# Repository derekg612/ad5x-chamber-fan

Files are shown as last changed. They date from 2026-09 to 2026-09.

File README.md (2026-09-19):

# AD5X Chamber Regulator

Three interchangeable builds of the same chamber controller, selected by PlatformIO environment:

| Environment | Board | Local UI | Fan control |
| --- | --- | --- | --- |
| `seeed_xiao_esp32c3` | Xiao ESP32-C3 | External 128x64 OLED + 2 buttons | On/off |
| `waveshare_esp32s3_touch_lcd_147` | Waveshare ESP32-S3-Touch-LCD-1.47 | Built-in 172x320 touchscreen | PWM speed control |
| `esp32_c3_oled_042` | Generic ESP32-C3 with 0.42" OLED | Onboard 72x40 OLED + 2 buttons | PWM speed control |

The 0.42" OLED build can also toggle the printer's chamber light over the network -- press both buttons at once.

All three share the same thermistor logic, Wi-Fi setup flow, and web UI. Build/upload a specific one with `pio run -e <environment> -t upload`; the Xiao environment is the default when no `-e` is given.

Wiring docs: [circuit-schematic.md](docs/circuit-schematic.md) (Xiao), [touch-lcd-schematic.md](docs/touch-lcd-schematic.md) (touchscreen), [c3-oled-042-schematic.md](docs/c3-oled-042-schematic.md) (0.42" OLED).

## Common behavior

On first boot, connect to the `AD5X-Chamber-Setup` Wi-Fi network using password `chamber123`, then follow the setup page to select the printer's Wi-Fi network. The saved connection is reused on later boots. Open the IP address printed to the serial monitor at 115200 baud, or shown on the display. Settings are saved in nonvolatile storage.

The fan turns on at `setpoint + upper threshold` and turns off at `setpoint - lower threshold`. A disconnected or out-of-range thermistor turns the fan on as a fail-safe.

## Xiao ESP32-C3 build (`seeed_xiao_esp32c3`)

- Xiao ESP32-C3, powered from the printer display's USB-A port (5 V/GND only)
- 10 kOhm NTC thermistor, Beta 3950
- 10 kOhm fixed resistor
- 24 V fan (no PWM input) mounted in the back panel, switched on/off through a 2N2222A NPN transistor (or BC337) on its ground return (return wire routed forward with the display ribbon cable), with a flyback diode across the fan
- 0.96" I2C SSD1306 128x64 OLED display
- 2 momentary buttons for local setpoint adjustment

Wire the thermistor and fixed resistor as a divider from 3.3 V to GND, with the midpoint on `D0`. The firmware assumes the thermistor is the high-side component and the fixed resistor is the low-side component. Connect the 2N2222A base to `D1` through a 330 Ohm resistor, share grounds, and power the fan continuously from an appropriate external 24 V supply. Do not power the fan through the Xiao.

Connect the OLED over I2C to `D4` (SDA) and `D5` (SCL), powered from `3V3`. Wire the two momentary buttons between `D2`/`D3` and `GND`; the firmware uses internal pull-ups, so no external resistors are needed. One button raises the setpoint, the other lowers it, in 0.5 degree C steps, with the change reflected immediately on the OLED and saved to nonvolatile storage.

## Waveshare ESP32-S3-Touch-LCD-1.47 build (`waveshare_esp32s3_touch_lcd_147`)

- Waveshare ESP32-S3-Touch-LCD-1.47 (built-in 172x320 touchscreen), powered from the printer display's USB-A port via its own USB-C port (5 V/GND only)
- 10 kOhm NTC thermistor, Beta 3950
- 10 kOhm fixed resistor
- 2-wire 24 V fan (0.29 A @ 24 V) mounted in the back panel, PWM speed-controlled through a 2N2222A NPN transistor (or BC337) on its ground return, with a 1N5819 Schottky across the fan

There's no separate OLED or physical buttons in this build -- the board's own display and capacitive touchscreen replace both. The UI runs in portrait orientation with the USB-C port at the bottom of the screen; two on-screen `-`/`+` buttons adjust the setpoint by 0.5 degree C per tap, the same step size and persistence behavior as the button build. Wire the thermistor to `GPIO4` and the 2N2222A base (through a 220 Ohm resistor) to `GPIO5`.

Unlike the Xiao build's on/off control, fan speed ramps proportionally between `setpoint - lower threshold` (idle) and `setpoint + upper threshold` (the configured maximum), with a duty floor so the fan doesn't sit below its stall speed. A maximum-fan-speed cap is available on the web settings page. All the fan drive parameters -- PWM frequency, duty floor, and an on/off fallback -- are `#define`s at the top of [src/main_s3touch.cpp](src/main_s3touch.cpp). See [docs/touch-lcd-schematic.md](docs/touch-lcd-schematic.md) for the full pinout, component sizing rationale, and the display/touch pins that are reserved internally.

## ESP32-C3 OLED 0.42" build (`esp32_c3_oled_042`)

- Generic ESP32-C3 board with an onboard 0.42" 72x40 SSD1306 OLED, powered from the printer display's USB-A port (5 V/GND only)
- 100 kOhm NTC thermistor, Beta 3950
- 100 kOhm fixed resistor
- 2-wire 24 V fan (0.29 A @ 24 V), PWM speed-controlled through a 2N2222A NPN transistor (or BC337) on its ground return, with a 1N5819 Schottky across the fan
- 2 momentary buttons for local setpoint adjustment and printer LED control

Same PWM fan control and `#define` knobs as the touchscreen build, but with a compact portrait display (mounted with the USB port on the left) and physical buttons. Thermistor on `IO2`, transistor base (via 220 Ohm) on `IO20`, and the setpoint up/down buttons on `IO1` and `IO4`. `IO20` is UART0's RX pin, which is free because this environment sends `Serial` over the board's native USB instead. The OLED occupies `IO5`/`IO6` internally (the board reference says `IO8`/`IO9`; see the schematic doc if the panel stays blank).

#### Printer LED toggle

Pressing **both buttons at once** toggles the printer's chamber light and shows the new state on the OLED for a moment. Neither button moves the setpoint while the other is down, and one long two-button press toggles exactly once.

Stock AD5X firmware does not expose Moonraker, so this talks to Flashforge's legacy command socket on TCP 8899, the same protocol as the `ad5x_send_command.py` helper script: commands framed with a leading `~` and CRLF, replies terminated by `ok`. Each toggle takes control (`M601 S1`), sends `M146 r255 g255 b255 F0` or `M146 r0 g0 b0 F0`, then hands control back (`M602`) so the printer's touchscreen is not left locked out. The printer will not report its light state back, so the firmware tracks what it last sent and persists it across reboots; if the light is changed at the printer, the first press afterwards may be a no-op.

The printer's hostname and port are on the web settings page, defaulting to `ad5x.lan:8899`. A failed toggle leaves the setting untouched and shows `fail` on the panel, with the detail on the serial monitor.

### Enclosure

[hardware/generate_c3_oled_case.py](hardware/generate_c3_oled_case.py) generates a two-part snap-fit case for this build:

```
~/.pythonenvs/stl/bin/python3 hardware/generate_c3_oled_case.py
```

It writes `case_bottom.stl` and `case_top.stl` alongside the script. The board is held without soldered headers, resting on a perimeter ledge and pressed down by pads on the lid, with 7 mm of headroom so the 2N2222A can lie flat on the PCB. Openings: USB-C on one end, a 6 mm circular cable hole in the middle of the tray floor -- the back panel -- for the fan return, ground bond, thermistor pair and button wires, and a window over the OLED. That hole opens into the relief under the board, so those wires solder to pads on the PCB's underside and drop straight out the back; there is only 1.2 mm of height in there, so they cannot run sideways first. Every dimension is a named constant at the top of the script, and `check_parameters()` asserts the ones that quietly ruin a print (wall left behind the snap groove, snap deflection, material bridging the wall openings, TO-92 headroom).

[hardware/preview_case.py](hardware/preview_case.py) renders the result for inspection:

```
~/.pythonenvs/stl/bin/python3 hardware/preview_case.py
```

It writes `preview_iso.png` (shaded views of each part plus an exploded view) and `preview_sections.png` (cuts through the assembled case). The section views are the useful ones -- they show the lip seated in the rebate, the snap ridge in its groove, the PCB on its ledge, and the material bridging the wall openings. Requires `matplotlib` in the same environment.

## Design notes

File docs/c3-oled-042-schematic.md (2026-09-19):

# ESP32-C3 OLED 0.42" Build

A generic ESP32-C3 board with an onboard 0.42" 72x40 SSD1306 OLED
([board reference](https://www.espboards.dev/esp32/esp32-c3-oled-042/)), with two external momentary buttons for setpoint adjustment. The fan circuit is identical to the touchscreen build -- 2N2222A (or BC337) low-side switch, 220 Ohm base resistor, 1N5819 Schottky, PWM speed control -- so see [touch-lcd-schematic.md](touch-lcd-schematic.md) for the component sizing rationale and [circuit-schematic.md](circuit-schematic.md) for the ground-bonding requirement. Both apply here unchanged.

## Pin budget

This board is unusually tight: of its 13 broken-out GPIOs, only IO0, IO1, IO3 and IO10 are free of strapping, JTAG or UART duty. The build uses:

| GPIO | Use | Notes |
| --- | --- | --- |
| IO1 | Setpoint-up button | Internal pull-up |
| IO2 | Thermistor divider midpoint | ADC1_CH2. Strapping pin -- see below. |
| IO4 | Setpoint-down button | Internal pull-up. JTAG TMS, free because JTAG goes over USB. |
| IO20 | 2N2222A base (via 220 Ohm) | PWM output. UART0 RX, free because Serial goes over USB. |

Reserved, do not reuse:

| GPIO | Function |
| --- | --- |
| IO5 | OLED I2C SDA (also JTAG TDI) |
| IO6 | OLED I2C SCL (also JTAG TCK) |
| IO8, IO9 | Strapping -- IO9 selects download mode at reset |
| IO18, IO19 | Native USB (the USB-C port) |

IO0, IO3, IO7, IO10 and IO21 are unused.

The board reference puts the OLED on IO8/IO9, but on the board this was built with it is wired to IO5/IO6, and boards sold under this name vary. If the panel stays blank, set `OLED_SDA_PIN`/`OLED_SCL_PIN` in `src/main_c3oled.cpp` to 8/9 and try again.

IO4, IO5 and IO6 being JTAG pins is harmless: the C3 routes JTAG through its built-in USB by default, so they behave as ordinary GPIO. IO8/IO9 are left unused, but they are still strapping pins, so don't add anything there that could pull them low at reset.

**Thermistor on IO2:** IO2 is listed as a strapping pin, but per Espressif's [hardware design guidelines](https://docs.espressif.com/projects/esp-hardware-design-guidelines/en/latest/esp32c3/schematic-checklist.html) it does not actually select the boot mode -- they only recommend pulling it high to guard against glitches. The divider holds it partway instead (about 1.65 V at 25 C, rising as the chamber warms), so this should be fine, but if boots are ever unreliable, move the thermistor to IO3 (also ADC1) and change `THERMISTOR_PIN`.

**Fan on IO20:** the USB-C port is wired to the C3's native USB, so flashing and the serial monitor never touch UART0 (IO20/IO21). The `esp32_c3_oled_042` environment sets `ARDUINO_USB_CDC_ON_BOOT=1` so that `Serial` also goes over USB, which leaves IO20 free. IO20 was picked over IO21 because it is an input during boot: IO21 is UART0 TX, which idles high and carries the boot log at every reset, so the fan would run and chatter for a moment before the firmware takes over. If the fan still twitches at power-up on IO20, add a 4.7-10 kOhm resistor from IO20 to GND.

## Wiring

```text
                         AD5X MAINBOARD AUX FAN PORT (BACK PANEL)

             +24 V  o----[ 1 A fuse ]----+--------------------+
                                         |                    |
                                         |                 +--+--+
                                         |                 | 24 V |
                                         |                 | FAN  |
                                         |                 +--+--+
                                         |                    |
                                         |                    +------|<|------+
                                         |                    |    1N5819     |
                                         |                    |               |
                                         |                              C  +---+---+
                                         |          IO20 --[220R]-------B  |2N2222A|
                                         |                              E  +---+---+
                                         |                                    |
             GND   o--------------------+------------------------------------+--- GND

             2N2222A (TO-92): E-B-C left to right, flat face toward you.

                         THERMISTOR INPUT (3.3 V ADC)

             3V3 o----[ 100 kOhm NTC, Beta 3950 ]----+----[ 100 kOhm ]----o GND
                                                      |
                                                      +--------------------- IO2

                         SETPOINT BUTTONS (momentary, to GND)

             IO1 o----[ momentary button ]---- GND     (setpoint up)
             IO4 o----[ momentary button ]---- GND     (setpoint down)
             Internal pull-ups enabled in firmware; no external resistors needed.

                         POWER

             Printer display USB-A +5 V  o------- board 5 V / VBUS
             Printer display USB-A GND   o------- board GND
```

## Display

The board is mounted in portrait with the USB port on the left and the screen facing you, so the 72x40 panel is drawn a quarter turn round as 40 pixels wide by 72 tall:

```
  NOW
  32.4
  SET
  35.0
  FAN
  45%
192.168.
  1.42
```

The current temperature is the largest reading (`fault` if the thermistor reading is invalid). Below it are the setpoint and the fan duty (`idle` when off), each with a tiny label above its value, since 40 pixels is only six characters wide in the value font. The IP address is split after its second octet so that even `255.255.255.255` fits.

Pressing both buttons shows `LIGHT` over `...` while the command is sent, then `ON`, `OFF`, or `fail` if the printer didn't reply.

If the text comes out upside down, the panel is mounted the other way round on your board: change `U8G2_R3` to `U8G2_R1` in the display constructor in `src/main_c3oled.cpp`.

## Important electrical notes

- Same ground-bonding requirement as the other builds: run a dedicated ground wire from the AD5X mainboard's real power ground to this board's ground bus. Do not rely on the display ribbon cable's ground pin.
- The 1N5819 flyback diode is required, installed directly across the fan.
- The 100 kOhm divider has a source impedance of around 50 kOhm, which is high enough for the ADC's sampling capacitor and fan-switching noise to pull readings around. A 100 nF ceramic capacitor from IO2 to GND, placed at the board, steadies it.
- An undriven IO20 (at boot, or if the firmware hangs) turns the fan off, not on. The firmware's sensor-fault fail-safe (full speed when the thermistor reading is invalid) still applies.
- Do not connect 24 V to any board GPIO, `3V3`, or `5V` pin.

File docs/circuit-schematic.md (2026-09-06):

# AD5X Chamber Regulator Circuit

This schematic uses the AD5X 24 V auxiliary fan supply, a plain (non-PWM) 24 V fan mounted in the back panel, a 2N2222A NPN transistor (or BC337 -- interchangeable here) as an on/off low-side switch, the printer display's USB-A port for 5 V/GND to the Xiao ESP32-C3, a 0.96" I2C SSD1306 128x64 OLED, and two momentary buttons for local setpoint adjustment.

The fan has no speed control input, so the Xiao switches it fully on or off instead of ramping speed. The fan's `+24 V` lead stays at the back panel, fused. The fan's `GND` return is run forward from the back panel (alongside the display ribbon cable) to the Xiao's control area, where the 2N2222A interrupts it to switch the fan. Because the 2N2222A is now switching real motor current, a flyback diode across the fan is required again to clamp the inductive kick when the transistor turns off.

The Xiao is powered from the printer display's USB-A port (5 V and GND only; D+/D- are unused) instead of a buck converter, since the display port already sits at logic-compatible 5 V.

```text
                         AD5X MAINBOARD AUX FAN PORT (BACK PANEL)
                         (VERIFY POLARITY AND VOLTAGE)

             +24 V  o----[ 1 A fuse ]----+--------------------+
                                         |                    |
                                         |                 +--+--+
                                         |                 | 24 V |
                                         |                 | FAN  |
                                         |                 +--+--+
                                         |                    |
                                         |                    +------|<|------+
                                         |                    |   flyback     |
                                         |                    |   diode       |
                                         |                    |               |
                                         |                    |  fan GND, run forward
                                         |                    |  alongside display
                                         |                    |  ribbon cable
                                         |                    |               |
                                         |                              C  +---+---+
                                         |            Xiao D1 --[330R]--B  |2N2222A|
                                         |                              E  +---+---+
                                         |                                  (or BC337)
                                         |                                    |
             GND   o--------------------+------------------------------------+--- GND

                         PRINTER DISPLAY USB-A PORT

             USB-A +5 V  o---------------------------------- Xiao 5V / VBUS
             USB-A GND   o---------------------------------- Xiao GND
             (D+/D- not connected)

                         THERMISTOR INPUT (3.3 V ADC)

             Xiao 3V3 o----[ 10 kOhm NTC, Beta 3950 ]----+----[ 10 kOhm ]----o Xiao GND
                                                         |
                                                         +---------------------- Xiao D0

             Optional: 100 nF capacitor from D0 to Xiao GND, placed near the Xiao.

                         0.96" I2C SSD1306 128x64 OLED

             OLED VCC  o---------------------------------- Xiao 3V3
             OLED GND  o---------------------------------- Xiao GND
             OLED SDA  o---------------------------------- Xiao D4
             OLED SCL  o---------------------------------- Xiao D5

                         SETPOINT BUTTONS (momentary, to GND)

             Xiao D2 o----[ momentary button ]---- GND     (setpoint up)
             Xiao D3 o----[ momentary button ]---- GND     (setpoint down)
             Internal pull-ups enabled in firmware; no external resistors needed.
```

## Connections

| Circuit point | Connect to |
| --- | --- |
| AD5X auxiliary fan `+24 V` | Fuse input, fan `+24 V` |
| Fan `GND` (motor return) | 2N2222A collector (wire routed with the display ribbon cable) |
| 2N2222A emitter | Common ground |
| Xiao `D1` | 330 Ohm base resistor, then 2N2222A base |
| Flyback diode cathode | Fan `+24 V` |
| Flyback diode anode | Fan `GND` / 2N2222A collector |
| Printer display USB-A `+5 V` | Xiao `5V`/`VBUS` pin |
| Printer display USB-A `GND` | Xiao `GND` |
| Thermistor divider midpoint | Xiao `D0` |
| OLED `VCC` | Xiao `3V3` |
| OLED `GND` | Xiao `GND` |
| OLED `SDA` | Xiao `D4` |
| OLED `SCL` | Xiao `D5` |
| Setpoint-up button | Xiao `D2` to `GND` |
| Setpoint-down button | Xiao `D3` to `GND` |

## Important electrical notes

- Measure the AD5X fan connector with a multimeter before wiring. Confirm it is approximately 24 V DC and identify polarity; do not rely on connector appearance alone.
- The 2N2222A (or BC337 -- either works here) is a plain NPN switch, not a logic-level MOSFET, so there's no gate-threshold uncertainty at 3.3 V. A TO-92 part marked "2N2222A" is really a PN2222A/P2N2222A equivalent, about 600 mA and 40 V, which is ample for this load. The 330 Ohm base resistor gives a forced beta of roughly 10-20 at typical small-fan currents (100-300 mA), enough to saturate it reliably. For the 0.29 A fan used in the touchscreen build, drop the base resistor to 220 Ohm for proper saturation margin.
- Pinout of the TO-92 2N2222A in hand: **E-B-C left to right**, flat face toward you with the leads pointing down (mirrors to C-B-E viewed from the rounded back). If you substitute a BC337, re-check first -- TO-92 pin assignments vary between part families and manufacturers, and a reversed emitter/collector still conducts weakly, so it appears half-working while running hot.
- The flyback diode must be rated for the fan's current and installed directly across the fan, reverse-biased during normal operation. This is required now that the 2N2222A switches real motor current, not just a logic signal.
- Verify the display USB-A port actually provides 5 V (not 3.3 V or a data-only pass-through). Do not add other 5 V loads to this port beyond the Xiao and OLED.
- **Do not rely on the display ribbon cable's ground pin as the system's common ground.** Measured continuity between the USB-A GND and the AD5X mainboard ground through the display cable can be tens of ohms (a thin signal-return trace, not a real ground bond) — nowhere near low enough to carry the fan's switched current or hold a stable ADC reference. Run a dedicated ground wire, comparable gauge to the fan wiring, directly from the AD5X mainboard's real power ground (the same GND the aux fan port uses) forward to the Xiao's ground bus, where it ties together the 2N2222A emitter, thermistor return, and OLED GND. That wire's low resistance dominates over the weak ribbon-cable path and establishes the actual common ground the circuit needs; the USB-A port then only needs to supply `5V`.
- Do not connect 24 V to any Xiao GPIO, `3V3`, `5V`, or `D+`/`D-` pin.
- Keep the 24 V fan wiring physically separate from the thermistor, OLED, and button wiring.
- The OLED and both buttons run at 3.3 V logic; do not substitute a 5 V-only OLED module without level shifting.
- Unlike the earlier PWM design, an undriven `D1` (GPIO low, at boot or if the firmware hangs) turns the 2N2222A off, which turns the fan off — there is no hardware fail-safe defaulting to full speed. The firmware's fail-safe (forcing the fan on when the thermistor reading is invalid) only covers sensor faults, not a hung MCU. The firmware turns the fan on if the thermistor reading is out of range, so a sensor or wiring fault fails toward ventilation.

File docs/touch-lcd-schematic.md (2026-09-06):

# Waveshare ESP32-S3-Touch-LCD-1.47 Build

This variant replaces the Xiao's external OLED and two physical buttons with the Waveshare ESP32-S3-Touch-LCD-1.47's built-in 172x320 capacitive touchscreen, and drives the fan with PWM speed control rather than plain on/off. The fan circuit topology is the same as the Xiao build (2N2222A or BC337 low-side switch on the fan's ground return, flyback diode, dedicated ground bonding wire), but the base resistor and diode are sized for PWM here -- see [Fan drive](#fan-drive-pwm-speed-control) below. The ground-bonding warning in [circuit-schematic.md](circuit-schematic.md) applies unchanged.

## Reserved pins (do not reuse)

These are wired internally on the board to the display and touch controller, confirmed from Waveshare's own Arduino example and community demo code for this exact board:

| Signal | GPIO |
| --- | --- |
| LCD MOSI | 39 |
| LCD SCK | 38 |
| LCD CS | 21 |
| LCD DC | 45 |
| LCD RST | 47 |
| LCD backlight | 46 |
| Touch SDA | 42 |
| Touch SCL | 41 |
| Touch RST | 47 (shared with LCD RST) |
| Touch INT | 48 |
| BOOT button | 0 |
| Battery ADC (unused here, no battery in this build) | 12 |

The module is an ESP32-S3R8 (8 MB octal PSRAM) with 16 MB flash, native USB (no separate USB-UART bridge chip), confirmed via `platformio.ini`'s `qio_opi` memory type setting.

## Our wiring (fan + thermistor)

```text
                         AD5X MAINBOARD AUX FAN PORT (BACK PANEL)
                         (VERIFY POLARITY AND VOLTAGE)

             +24 V  o----[ 1 A fuse ]----+--------------------+
                                         |                    |
                                         |                 +--+--+
                                         |                 | 24 V |
                                         |                 | FAN  |
                                         |                 +--+--+
                                         |                    |
                                         |                    +------|<|------+
                                         |                    |   flyback     |
                                         |                    |   diode       |
                                         |                    |               |
                                         |                    |  fan GND, run forward
                                         |                    |  to the board
                                         |                    |               |
                                         |                              C  +---+---+
                                         |         GPIO5 --[220R]--------B  |2N2222A|
                                         |                              E  +---+---+
                                         |                                  (or BC337)

             2N2222A (TO-92) physical pinout -- flat/marked face toward you,
             leads pointing down. Confirmed on the actual parts in hand:

                       +-------+
                       |2N2222A|         E (left)   -> common ground
                       +-------+         B (middle) -> 220R -> GPIO5
                        |  |  |          C (right)  -> fan GND return
                        E  B  C

             Viewed from the rounded back instead, this order mirrors to C-B-E.
                                         |                                    |
             GND   o--------------------+------------------------------------+--- GND

                         THERMISTOR INPUT (3.3 V ADC)

             3V3 o----[ 10 kOhm NTC, Beta 3950 ]----+----[ 10 kOhm ]----o GND
                                                     |
                                                     +---------------------- GPIO4

             Optional: 100 nF capacitor from GPIO4 to GND, placed near the board.

                         POWER (from printer display USB-A, via this board's USB-C)

             USB-A +5 V  o---------------------------------- board USB-C (VBUS)
             USB-A GND   o---------------------------------- board USB-C (GND)
```

## Connections

| Circuit point | Connect to |
| --- | --- |
| AD5X auxiliary fan `+24 V` | Fuse input, fan `+24 V` |
| Fan `GND` (motor return) | 2N2222A collector |
| 2N2222A emitter | Common ground |
| Board `GPIO5` | 220 Ohm base resistor, then 2N2222A base |
| 1N5819 Schottky cathode | Fan `+24 V` |
| 1N5819 Schottky anode | Fan `GND` / 2N2222A collector |
| Thermistor divider midpoint | Board `GPIO4` |
| Printer display USB-A `+5 V` / `GND` | Board's own USB-C connector |

## UI

The screen runs in portrait orientation (172 wide x 320 tall) with the USB-C port at the bottom. It shows the current temperature, the setpoint, and fan state, with two large on-screen buttons at the bottom of the screen (`-` and `+`) that nudge the setpoint by 0.5 degree C per tap -- the same step size, debounce behavior, and NVS persistence as the physical buttons in the Xiao build. The web UI (same page/settings routes as the Xiao build) is also still available over Wi-Fi.

**Orientation is a firmware assumption, not a confirmed fact** -- `DISPLAY_ROTATION` in `src/main_s3touch.cpp` is set to `2` based on the vendor demo's default (`0`) placing the USB-C at the top; rotating 180 degrees should put it at the bottom. Verify this on first boot: if the UI renders upside down, change `DISPLAY_ROTATION` to `0` and re-flash. The touch driver is initialized with the same rotation value so touch coordinates stay aligned with what's drawn.

## Fan drive (PWM speed control)

The fan is a 2-wire 24 V unit rated 0.29 A @ 24 V over a 16-26.4 V supply range, and its speed is controlled by chopping its supply with the 2N2222A (or BC337) at 25 kHz. Speed ramps proportionally between `setpoint - lower threshold` (idle) and `setpoint + upper threshold` (the configured maximum), with a 25% duty floor so the fan doesn't sit below its stall speed. All the knobs are `#define`s at the top of `src/main_s3touch.cpp`:

| Define | Default | Purpose |
| --- | --- | --- |
| `FAN_PWM_ENABLED` | `1` | Set to `0` for plain on/off switching |
| `FAN_PWM_FREQUENCY_HZ` | `25000` | Above the audible band; lower it to cut switching loss |
| `FAN_PWM_RESOLUTION_BITS` | `8` | LEDC duty resolution (0-255) |
| `FAN_MIN_DUTY_PERCENT` | `25` | Stall floor once the fan is asked to run |
| `FAN_SPEED_CAP_MIN_PERCENT` | `25` | Lower bound of the web UI's max-speed setting |

Unlike the earlier 4-wire PWM design, this drive is **not** inverted: `GPIO5` high turns the 2N2222A on and powers the fan, so duty maps straight through.

### Component choices for PWM

- **2N2222A (TO-92), or BC337**: at 0.29 A and a 26.4 V worst-case rail these are the only suitable NPNs from the on-hand parts, and they're interchangeable in this circuit. The 2N2222A is the default here because it's a purpose-built switching transistor and turns off faster, which suits 25 kHz PWM slightly better. Note that a TO-92 part marked "2N2222A" is really a PN2222A/P2N2222A equivalent (about 600 mA, 40 V) rather than the 800 mA TO-18 original -- still ample for 0.29 A. Rejected alternatives: the S8050's 25 V Vceo sits below the fan's own maximum supply voltage; the 2N3904 (200 mA) and C1815/A1015 (150 mA) can't carry the current; the rest of the on-hand parts are PNP.
- **Pinout**: the TO-92 2N2222A in hand is **E-B-C left to right** with the flat face toward you and the leads down (the standard P2N2222A order), as drawn above. If you substitute a BC337, re-check first -- TO-92 pin assignments vary between part families and manufacturers, and a reversed emitter/collector still conducts weakly (reverse beta of only a few), so it looks half-working while running hot. To verify any unknown part: in diode mode the base is the pin reading ~0.7 V forward to both others, and an hFE socket reads in the hundreds when oriented correctly versus single digits when reversed.
- **220 Ohm base resistor**: gives roughly 11 mA of base drive (forced beta ~26 at 0.29 A), enough to saturate either transistor while staying well inside the ESP32-S3's per-pin current limit. The earlier 330 Ohm value was sized before the fan's real current was known and is too weak here.
- **1N5819 Schottky flyback**: required, and it must be fast. Under PWM this diode conducts 25,000 times a second; a standard rectifier like a 1N4007, whose reverse recovery is measured in microseconds, would spend a large fraction of each cycle effectively shorting the rail. The Schottky's near-zero recovery time is what makes chopping the supply safe.
- Expect roughly 200 mW total dissipation in the transistor (conduction plus switching loss) -- comfortable for a TO-92 package, but if it runs hot, lowering `FAN_PWM_FREQUENCY_HZ` cuts the switching half of that proportionally.

## Important electrical notes

- Same ground-bonding requirement as the Xiao build: do not rely on the display ribbon cable's ground pin as the common ground for the fan-switching circuit. Run a dedicated ground wire from the AD5X mainboard's real power ground to this board's ground bus.
- The 1N5819 flyback diode is required, installed directly across the fan.
- Chopping a 2-wire brushless fan's supply is fan-dependent. This fan is specified as PWM-controllable, but if it stutters, whines, or won't start at low duty, try lowering `FAN_PWM_FREQUENCY_HZ`, raising `FAN_MIN_DUTY_PERCENT`, or setting `FAN_PWM_ENABLED` to `0`.
- As with the Xiao build, an undriven `GPIO5` (at boot, or if the firmware hangs) turns the fan off, not on -- there's no hardware fail-safe defaulting to full speed. The firmware's sensor-fault fail-safe (full speed when the thermistor reading is invalid, ignoring the configured cap) still applies.
- Do not connect 24 V to any board GPIO, `3V3`, or USB-C pin.

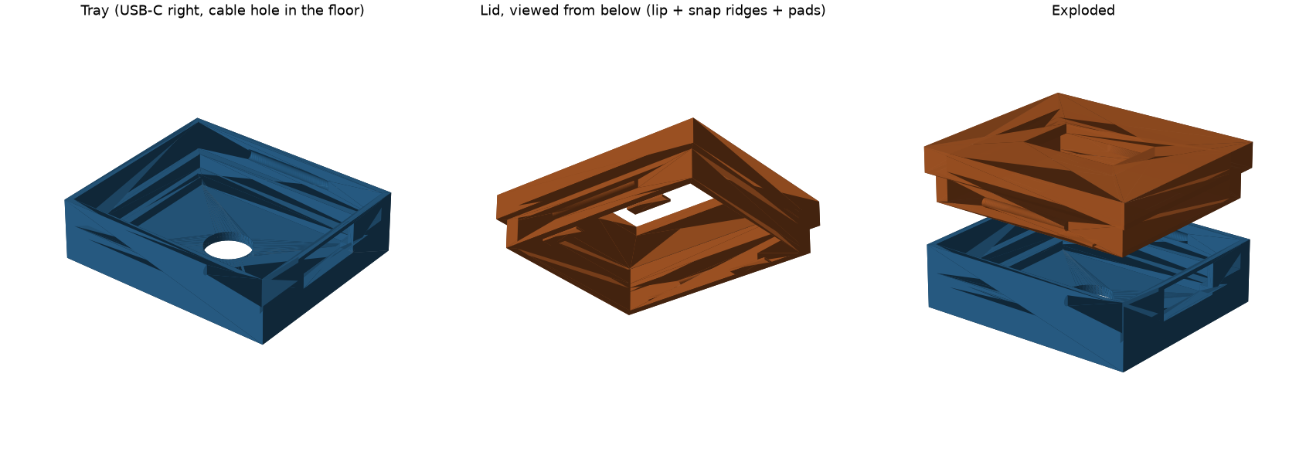
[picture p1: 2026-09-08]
hardware/preview_iso.png

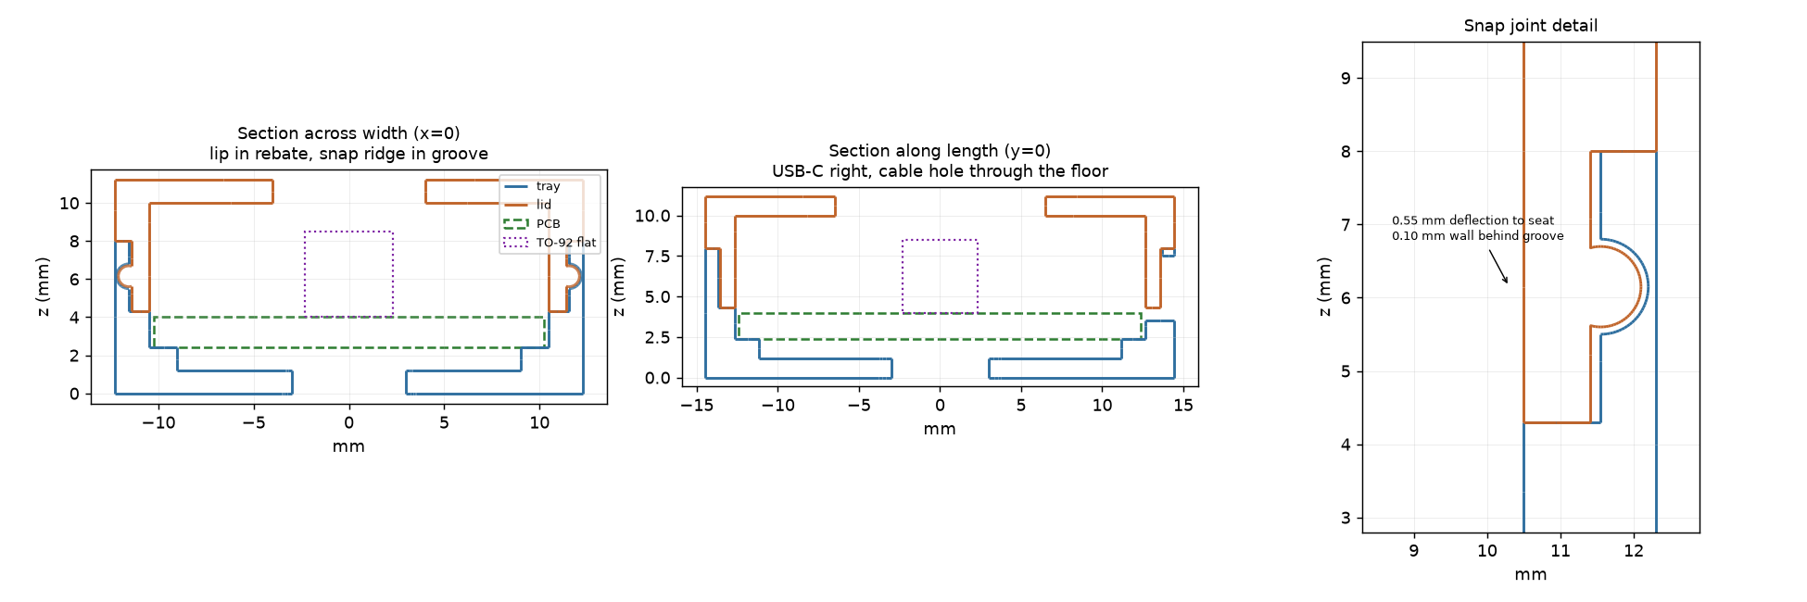
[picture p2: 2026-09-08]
hardware/preview_sections.png

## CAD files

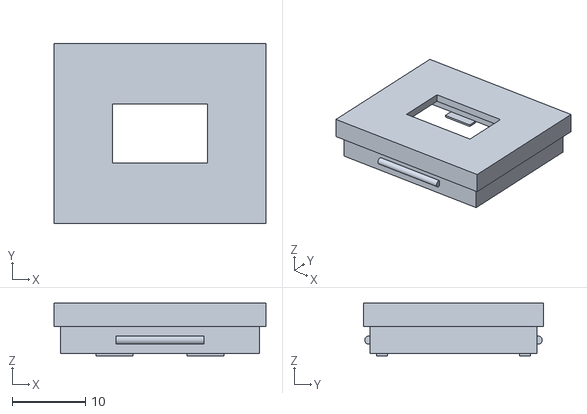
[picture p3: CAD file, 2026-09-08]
hardware/case_top.stl
28.9 x 24.6 x 7.20

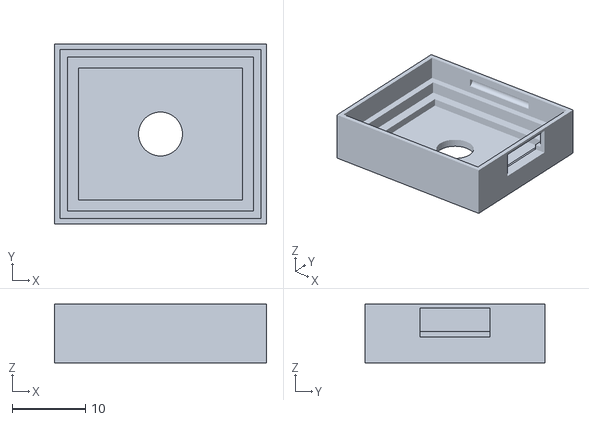
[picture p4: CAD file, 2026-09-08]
hardware/case_bottom.stl
28.9 x 24.6 x 8.00

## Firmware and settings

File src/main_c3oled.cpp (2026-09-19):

#include <Arduino.h>
#include <DNSServer.h>
#include <ESPAsyncWebServer.h>
#include <ESPAsyncWiFiManager.h>
#include <Preferences.h>
#include <U8g2lib.h>
#include <WiFi.h>
#include <WiFiClient.h>
#include <Wire.h>

// Generic ESP32-C3 board with an onboard 0.42" 72x40 SSD1306 OLED.
//
// The OLED sits on IO5/IO6 (JTAG pins, usable as GPIO because JTAG goes over
// the built-in USB). The board reference says IO8/IO9 instead; if the panel
// stays blank, try 8 and 9 here.
//
// The thermistor has to be on an ADC1 pin (IO0-IO4). IO2 is a strapping pin,
// though it does not select the boot mode -- Espressif only recommends a
// pull-up there against glitches. If boots are ever unreliable, use IO3.
//
// The fan is on IO20, UART0's RX pin. That only works because this build sends
// Serial over the native USB (ARDUINO_USB_CDC_ON_BOOT in platformio.ini), so
// UART0 is never started. IO20 is an input during boot, so the fan stays off
// until the firmware takes it; IO21 (TX) would chatter with the boot log.
constexpr uint8_t OLED_SDA_PIN = 5;
constexpr uint8_t OLED_SCL_PIN = 6;
constexpr uint8_t THERMISTOR_PIN = 2;   // ADC1_CH2
constexpr uint8_t FAN_PIN = 20;
constexpr uint8_t BUTTON_UP_PIN = 1;
constexpr uint8_t BUTTON_DOWN_PIN = 4;

// The board is mounted in portrait with the USB port on the left, so the
// 72x40 panel is drawn rotated a quarter turn as 40 wide by 72 tall. If the
// text comes out upside down, the panel sits the other way round on your
// board: change U8G2_R3 to U8G2_R1 in the display constructor below.
constexpr uint8_t DISPLAY_WIDTH = 40;
constexpr uint8_t DISPLAY_HEIGHT = 72;

// ---------------------------------------------------------------------------
// Fan drive configuration -- identical to the touchscreen build.
//
// The fan is a 2-wire 24 V unit (0.29 A @ 24 V, 16-26.4 V range) whose supply
// is chopped by a 2N2222A (or BC337) on its ground return, with a 1N5819
// Schottky across the fan. This drive is NOT inverted: driving FAN_PIN high
// turns the transistor on and powers the fan, so duty maps straight through.
//
// Set FAN_PWM_ENABLED to 0 to fall back to plain on/off switching.
// ---------------------------------------------------------------------------
#define FAN_PWM_ENABLED 1
// 25 kHz keeps switching above the audible band. Lower it (e.g. 1000) if the
// transistor runs hot -- switching loss scales with frequency.
#define FAN_PWM_FREQUENCY_HZ 25000
#define FAN_PWM_RESOLUTION_BITS 8
// Small fans stall or stutter below roughly this duty, so once the fan is
// asked to run at all it ramps from this floor rather than from zero.
#define FAN_MIN_DUTY_PERCENT 25.0f
#define FAN_MAX_DUTY_PERCENT 100.0f
// Bounds for the user-configurable speed cap on the settings page.
#define FAN_SPEED_CAP_MIN_PERCENT 25.0f
#define FAN_SPEED_CAP_DEFAULT_PERCENT 100.0f

constexpr char SETUP_AP_NAME[] = "AD5X-Chamber-Setup";
constexpr char SETUP_AP_PASSWORD[] = "chamber123";
constexpr float SERIES_RESISTOR_OHMS = 100000.0f;
constexpr float THERMISTOR_NOMINAL_OHMS = 100000.0f;
constexpr float NOMINAL_TEMPERATURE_C = 25.0f;
constexpr float THERMISTOR_BETA = 3950.0f;
constexpr float ADC_REFERENCE_VOLTS = 3.3f;
constexpr float SETPOINT_MIN_C = 10.0f;
constexpr float SETPOINT_MAX_C = 60.0f;
constexpr float DEFAULT_SETPOINT_C = 35.0f;
constexpr float DEFAULT_TOP_OFFSET_C = 3.0f;
constexpr float DEFAULT_BOTTOM_OFFSET_C = 1.0f;
constexpr unsigned long SAMPLE_INTERVAL_MS = 2000;
constexpr float SETPOINT_STEP_C = 0.5f;
constexpr unsigned long BUTTON_DEBOUNCE_MS = 250;
// A single button only acts once it has been down this long on its own, so
// that a two-button press whose halves land a few milliseconds apart toggles
// the printer LED instead of first nudging the setpoint.
constexpr unsigned long BUTTON_COMBO_GUARD_MS = 120;

// ---------------------------------------------------------------------------
// Printer LED control -- pressing both buttons at once toggles the AD5X's
// chamber light.
//
// Stock AD5X firmware does not expose Moonraker; what it does expose is
// Flashforge's legacy command socket on TCP 8899, which speaks a fixed G/M
// code dialect. Commands are framed with a leading '~' and CRLF, and every
// reply ends with a line reading "ok". A remote client has to take control
// (M601 S1) before the firmware will accept anything, and should hand it back
// (M602) afterwards so the printer's own touchscreen keeps working.
// This mirrors ad5x_send_command.py.
// ---------------------------------------------------------------------------
constexpr char DEFAULT_PRINTER_HOST[] = "ad5x.lan";
constexpr uint16_t DEFAULT_PRINTER_PORT = 8899;
constexpr int32_t PRINTER_CONNECT_TIMEOUT_MS = 1500;
constexpr unsigned long PRINTER_REPLY_TIMEOUT_MS = 1200;
constexpr char PRINTER_LED_ON_COMMAND[] = "M146 r255 g255 b255 F0";
constexpr char PRINTER_LED_OFF_COMMAND[] = "M146 r0 g0 b0 F0";
constexpr char PRINTER_TAKE_CONTROL_COMMAND[] = "M601 S1";
constexpr char PRINTER_RELEASE_CONTROL_COMMAND[] = "M602";
constexpr char PRINTER_REPLY_TERMINATOR[] = "ok";
// How long the two-line confirmation stays on the panel before the normal
// readout comes back.
constexpr unsigned long FLASH_MESSAGE_MS = 1500;

AsyncWebServer server(80);
DNSServer dns;
Preferences preferences;
U8G2_SSD1306_72X40_ER_F_HW_I2C display(U8G2_R3, U8X8_PIN_NONE, OLED_SCL_PIN, OLED_SDA_PIN);

float setpointC = DEFAULT_SETPOINT_C;
float topOffsetC = DEFAULT_TOP_OFFSET_C;
float bottomOffsetC = DEFAULT_BOTTOM_OFFSET_C;
float maxFanSpeedPercent = FAN_SPEED_CAP_DEFAULT_PERCENT;
float temperatureC = NAN;
uint8_t fanDutyPercent = 0;
unsigned long lastSampleMs = 0;
unsigned long lastButtonUpMs = 0;
unsigned long lastButtonDownMs = 0;
unsigned long buttonUpSinceMs = 0;
unsigned long buttonDownSinceMs = 0;
bool buttonUpHeld = false;
bool buttonDownHeld = false;
// Set when both buttons are down together, cleared only once both are
// released, so one long two-button press toggles the LED exactly once.
bool buttonComboHandled = false;

String printerHost = DEFAULT_PRINTER_HOST;
uint16_t printerPort = DEFAULT_PRINTER_PORT;
// The printer will not report its light state back, so this tracks what we
// last told it. It is persisted so the toggle stays in step across reboots.
bool printerLedOn = true;

String flashLine1;
String flashLine2;
unsigned long flashUntilMs = 0;

float readTemperatureC() {
  const int raw = analogRead(THERMISTOR_PIN);
  if (raw <= 0 || raw >= 4095) {
    return NAN;
  }

  const float voltage = (static_cast<float>(raw) / 4095.0f) * ADC_REFERENCE_VOLTS;
  const float resistance = SERIES_RESISTOR_OHMS * voltage / (ADC_REFERENCE_VOLTS - voltage);
  const float steinhart = log(resistance / THERMISTOR_NOMINAL_OHMS) / THERMISTOR_BETA
      + 1.0f / (NOMINAL_TEMPERATURE_C + 273.15f);
  return 1.0f / steinhart - 273.15f;
}

void updateFan() {
  const float topC = setpointC + topOffsetC;
  const float bottomC = setpointC - bottomOffsetC;
  float requestedPercent;

  if (isnan(temperatureC)) {
    // Sensor fault: ignore the configured cap and force full ventilation.
    requestedPercent = FAN_MAX_DUTY_PERCENT;
  } else if (temperatureC <= bottomC) {
    requestedPercent = 0.0f;
  } else if (temperatureC >= topC) {
    requestedPercent = maxFanSpeedPercent;
  } else {
    const float floorPercent = min(static_cast<float>(FAN_MIN_DUTY_PERCENT), maxFanSpeedPercent);
    const float fraction = (temperatureC - bottomC) / (topC - bottomC);
    requestedPercent = floorPercent + fraction * (maxFanSpeedPercent - floorPercent);
  }

  fanDutyPercent = static_cast<uint8_t>(
      lroundf(constrain(requestedPercent, 0.0f, FAN_MAX_DUTY_PERCENT)));

#if FAN_PWM_ENABLED
  constexpr uint32_t fullScale = (1u << FAN_PWM_RESOLUTION_BITS) - 1u;
  ledcWrite(FAN_PIN, static_cast<uint32_t>(lroundf(fanDutyPercent * fullScale / 100.0f)));
#else
  digitalWrite(FAN_PIN, fanDutyPercent > 0 ? HIGH : LOW);
#endif
}

void persistSettings() {
  preferences.putFloat("setpoint", setpointC);
  preferences.putFloat("topOffset", topOffsetC);
  preferences.putFloat("bottomOffset", bottomOffsetC);
  preferences.putFloat("maxFanSpeed", maxFanSpeedPercent);
  preferences.putString("printerHost", printerHost);
  preferences.putUShort("printerPort", printerPort);
}

// Text is positioned by its top edge (setFontPosTop in setup) and centered
// across the panel's width.
void drawCentered(int y, const String &text) {
  display.drawStr((DISPLAY_WIDTH - display.getStrWidth(text.c_str())) / 2, y, text.c_str());
}

// The portrait panel is only 40 pixels wide -- six characters of the 6x10
// font -- so each reading gets a tiny label above its value rather than
// sharing a line with it. Current temperature is the largest. The IP address
// is too wide for one line and is split after its second octet.
void updateDisplay() {
  display.firstPage();
  do {
    if (flashUntilMs != 0) {
      display.setFont(u8g2_font_6x10_tf);
      drawCentered(24, flashLine1);
      display.setFont(u8g2_font_7x13B_tf);
      drawCentered(38, flashLine2);
      continue;
    }
    display.setFont(u8g2_font_4x6_tf);
    drawCentered(0, "NOW");
    drawCentered(20, "SET");
    drawCentered(37, "FAN");
    display.setFont(u8g2_font_7x13B_tf);
    drawCentered(7, isnan(temperatureC) ? String("fault") : String(temperatureC, 1));
    display.setFont(u8g2_font_6x10_tf);
    drawCentered(27, String(setpointC, 1));
    drawCentered(44, fanDutyPercent == 0 ? String("idle") : String(fanDutyPercent) + "%");
    const String ip = WiFi.localIP().toString();
    const int split = ip.indexOf('.', ip.indexOf('.') + 1) + 1;
    display.setFont(u8g2_font_5x8_tf);
    drawCentered(55, ip.substring(0, split));
    drawCentered(63, ip.substring(split));
  } while (display.nextPage());
}

void showFlash(const char *line1, const char *line2) {
  flashLine1 = line1;
  flashLine2 = line2;
  flashUntilMs = millis() + FLASH_MESSAGE_MS;
  updateDisplay();
}

// Send one framed command and wait for the terminating "ok".
bool sendPrinterCommand(WiFiClient &client, const char *command) {
  client.printf("~%s\r\n", command);
  String reply;
  const unsigned long deadline = millis() + PRINTER_REPLY_TIMEOUT_MS;
  while (static_cast<long>(millis() - deadline) < 0) {
    while (client.available() > 0) {
      reply += static_cast<char>(client.read());
    }
    reply.trim();
    if (reply.endsWith(PRINTER_REPLY_TERMINATOR)) {
      return true;
    }
    if (!client.connected() && client.available() == 0) {
      break;
    }
    delay(5);
  }
  Serial.printf("Printer did not acknowledge %s (reply: %s)\n", command, reply.c_str());
  return false;
}

// Flip the printer's chamber light. Blocks for up to a few seconds in the
// worst case; the async web server runs on its own task, so only the button
// and sampling loop waits.
bool togglePrinterLed() {
  if (WiFi.status() != WL_CONNECTED) {
    Serial.println("Cannot toggle the printer LED: no Wi-Fi.");
    return false;
  }

  WiFiClient client;
  if (!client.connect(printerHost.c_str(), printerPort, PRINTER_CONNECT_TIMEOUT_MS)) {
    Serial.printf("Cannot reach %s:%u\n", printerHost.c_str(), printerPort);
    return false;
  }

  const bool turnOn = !printerLedOn;
  bool ok = sendPrinterCommand(client, PRINTER_TAKE_CONTROL_COMMAND);
  if (ok) {
    ok = sendPrinterCommand(client, turnOn ? PRINTER_LED_ON_COMMAND : PRINTER_LED_OFF_COMMAND);
  }
  // Hand control back either way, so a failed toggle does not leave the
  // printer's own touchscreen locked out.
  sendPrinterCommand(client, PRINTER_RELEASE_CONTROL_COMMAND);
  client.stop();

  if (ok) {
    printerLedOn = turnOn;
    preferences.putBool("printerLedOn", printerLedOn);
    Serial.printf("Printer LED %s\n", printerLedOn ? "on" : "off");
  }
  return ok;
}

void adjustSetpoint(float deltaC) {
  setpointC = constrain(setpointC + deltaC, SETPOINT_MIN_C, SETPOINT_MAX_C);
  persistSettings();
  updateFan();
  updateDisplay();
}

void handleButtons() {
  const unsigned long now = millis();
  const bool upDown = digitalRead(BUTTON_UP_PIN) == LOW;
  const bool downDown = digitalRead(BUTTON_DOWN_PIN) == LOW;

  if (upDown && !buttonUpHeld) {
    buttonUpSinceMs = now;
  }
  if (downDown && !buttonDownHeld) {
    buttonDownSinceMs = now;
  }
  buttonUpHeld = upDown;
  buttonDownHeld = downDown;

  // Both buttons: toggle the printer's chamber light, once per press.
  if (upDown && downDown) {
    if (!buttonComboHandled) {
      buttonComboHandled = true;
      showFlash("LIGHT", "...");
      if (togglePrinterLed()) {
        showFlash("LIGHT", printerLedOn ? "ON" : "OFF");
      } else {
        showFlash("LIGHT", "fail");
      }
    }
    return;
  }
  if (buttonComboHandled) {
    // Ignore whichever button is still down after the combo, so releasing
    // them a moment apart does not move the setpoint.
    if (!upDown && !downDown) {
      buttonComboHandled = false;
      lastButtonUpMs = now;
      lastButtonDownMs = now;
    }
    return;
  }

  if (upDown && now - buttonUpSinceMs >= BUTTON_COMBO_GUARD_MS
      && now - lastButtonUpMs >= BUTTON_DEBOUNCE_MS) {
    lastButtonUpMs = now;
    adjustSetpoint(SETPOINT_STEP_C);
  }
  if (downDown && now - buttonDownSinceMs >= BUTTON_COMBO_GUARD_MS
      && now - lastButtonDownMs >= BUTTON_DEBOUNCE_MS) {
    lastButtonDownMs = now;
    adjustSetpoint(-SETPOINT_STEP_C);
  }
}

String page() {
  const String temperature = isnan(temperatureC) ? "Sensor fault" : String(temperatureC, 1) + " &deg;C";
  const String state = fanDutyPercent == 0 ? String("IDLE") : String(fanDutyPercent) + "% speed";
  return String(F("<!doctype html><html><head><meta name='viewport' content='width=device-width,initial-scale=1'>"
           "<title>AD5X Chamber</title><style>body{font-family:system-ui;max-width:34rem;margin:2rem auto;padding:0 1rem;color:#17212b}"
           "main{border:1px solid #ccd5dc;border-radius:8px;padding:1.25rem}h1{margin-top:0}label{display:block;margin-top:1rem}"
           "input,button{font:inherit;padding:.55rem;margin-top:.3rem;width:100%;box-sizing:border-box}button{margin-top:1.25rem;background:#1769aa;color:white;border:0;border-radius:4px}"
           ".reading{font-size:2rem;font-weight:700}.state{font-weight:700;color:#1769aa}</style></head><body><main><h1>AD5X Chamber</h1><div class='reading'>"))
      + temperature + F("</div><p>Fan: <span class='state'>") + state
      + F("</span></p><form method='post' action='/settings'><label>Target temperature (&deg;C)<input name='setpoint' type='number' step='0.5' min='10' max='60' value='")
      + String(setpointC, 1) + F("'></label><label>Upper threshold above target (&deg;C)<input name='top' type='number' step='0.5' min='0.5' max='20' value='")
      + String(topOffsetC, 1) + F("'></label><label>Lower threshold below target (&deg;C)<input name='bottom' type='number' step='0.5' min='0.5' max='20' value='")
      + String(bottomOffsetC, 1) + F("'></label><label>Maximum fan speed (%)<input name='maxfan' type='number' step='5' min='")
      + String(FAN_SPEED_CAP_MIN_PERCENT, 0) + F("' max='") + String(FAN_MAX_DUTY_PERCENT, 0) + F("' value='")
      + String(maxFanSpeedPercent, 0) + F("'></label><label>Printer host<input name='printerhost' type='text' value='")
      + printerHost + F("'></label><label>Printer port<input name='printerport' type='number' min='1' max='65535' value='")
      + String(printerPort) + F("'></label><p>Press both buttons together to toggle the printer LED (last set <span class='state'>")
      + (printerLedOn ? F("ON") : F("OFF")) + F("</span>).</p><button type='submit'>Save settings</button></form></main></body></html>");
}

void handleSettings(AsyncWebServerRequest *request) {
  if (request->hasParam("setpoint", true)) {
    setpointC = constrain(request->getParam("setpoint", true)->value().toFloat(), SETPOINT_MIN_C, SETPOINT_MAX_C);
  }
  if (request->hasParam("top", true)) {
    topOffsetC = constrain(request->getParam("top", true)->value().toFloat(), 0.5f, 20.0f);
  }
  if (request->hasParam("bottom", true)) {
    bottomOffsetC = constrain(request->getParam("bottom", true)->value().toFloat(), 0.5f, 20.0f);
  }
  if (request->hasParam("maxfan", true)) {
    maxFanSpeedPercent = constrain(request->getParam("maxfan", true)->value().toFloat(),
        FAN_SPEED_CAP_MIN_PERCENT, FAN_MAX_DUTY_PERCENT);
  }
  if (request->hasParam("printerhost", true)) {
    String host = request->getParam("printerhost", true)->value();
    host.trim();
    if (host.length() > 0) {
      printerHost = host;
    }
  }
  if (request->hasParam("printerport", true)) {
    const long port = request->getParam("printerport", true)->value().toInt();
    if (port > 0 && port <= 65535) {
      printerPort = static_cast<uint16_t>(port);
    }
  }
  persistSettings();
  updateFan();
  updateDisplay();
  request->redirect("/");
}

void setup() {
  Serial.begin(115200);
#if FAN_PWM_ENABLED
  ledcAttach(FAN_PIN, FAN_PWM_FREQUENCY_HZ, FAN_PWM_RESOLUTION_BITS);
  ledcWrite(FAN_PIN, 0);
#else
  pinMode(FAN_PIN, OUTPUT);
  digitalWrite(FAN_PIN, LOW);
#endif
  analogReadResolution(12);

  pinMode(BUTTON_UP_PIN, INPUT_PULLUP);
  pinMode(BUTTON_DOWN_PIN, INPUT_PULLUP);

  Wire.begin(OLED_SDA_PIN, OLED_SCL_PIN);
  display.begin();
  display.setFontPosTop();
  display.firstPage();
  do {
    display.setFont(u8g2_font_7x13B_tf);
    drawCentered(22, "AD5X");
    display.setFont(u8g2_font_5x8_tf);
    drawCentered(40, "Wi-Fi...");
  } while (display.nextPage());

  preferences.begin("chamber", false);
  setpointC = preferences.getFloat("setpoint", DEFAULT_SETPOINT_C);
  topOffsetC = preferences.getFloat("topOffset", DEFAULT_TOP_OFFSET_C);
  bottomOffsetC = preferences.getFloat("bottomOffset", DEFAULT_BOTTOM_OFFSET_C);
  maxFanSpeedPercent = preferences.getFloat("maxFanSpeed", FAN_SPEED_CAP_DEFAULT_PERCENT);
  printerHost = preferences.getString("printerHost", DEFAULT_PRINTER_HOST);
  printerPort = preferences.getUShort("printerPort", DEFAULT_PRINTER_PORT);
  printerLedOn = preferences.getBool("printerLedOn", true);

  WiFi.setHostname("AD5X-Chamber");
  AsyncWiFiManager wifiManager(&server, &dns);
 if (!wifiManager.autoConnect(SETUP_AP_NAME, SETUP_AP_PASSWORD)) {
    Serial.println("Wi-Fi setup failed; restarting.");
    delay(1000);
    ESP.restart();
  }
  WiFi.setAutoReconnect(true);
  Serial.print("Open http://");
  Serial.println(WiFi.localIP());

  updateDisplay();

  server.on("/", HTTP_GET, [](AsyncWebServerRequest *request) {
    request->send(200, "text/html", page());
  });
  server.on("/settings", HTTP_POST, handleSettings);
  server.begin();
}

void loop() {
  handleButtons();

  if (flashUntilMs != 0 && static_cast<long>(millis() - flashUntilMs) >= 0) {
    flashUntilMs = 0;
    updateDisplay();
  }

  if (millis() - lastSampleMs >= SAMPLE_INTERVAL_MS) {
    lastSampleMs = millis();
    temperatureC = readTemperatureC();
    updateFan();
    updateDisplay();
    Serial.printf("Temperature: %.1f C, fan: %u%%\n", temperatureC, fanDutyPercent);
  }
}

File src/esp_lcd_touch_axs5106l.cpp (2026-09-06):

#include "esp_lcd_touch_axs5106l.h"

static TwoWire *g_touch_i2c;
static uint16_t g_width;
static uint16_t g_height;
static uint16_t g_rotation;
static touch_data_t g_touch_data;
static volatile bool g_touch_int_flag = false;

static bool touch_i2c_read(uint8_t driver_addr, uint8_t reg_addr, uint8_t *data, uint32_t length) {
  g_touch_i2c->beginTransmission(driver_addr);
  g_touch_i2c->write(reg_addr);
  if (g_touch_i2c->endTransmission() != 0) {
    return false;
  }
  g_touch_i2c->requestFrom(driver_addr, length);
  if (g_touch_i2c->available() != static_cast<int>(length)) {
    return false;
  }
  g_touch_i2c->readBytes(data, length);
  return true;
}

static void IRAM_ATTR touch_int_cb() {
  g_touch_int_flag = true;
}

void bsp_touch_init(TwoWire *touch_i2c, int tp_rst, int tp_int, uint16_t rotation, uint16_t width, uint16_t height) {
  g_touch_i2c = touch_i2c;
  g_width = width;
  g_height = height;
  g_rotation = rotation;

  pinMode(tp_rst, OUTPUT);
  digitalWrite(tp_rst, LOW);
  delay(200);
  digitalWrite(tp_rst, HIGH);
  delay(300);

  pinMode(tp_int, INPUT);
  attachInterrupt(tp_int, touch_int_cb, FALLING);

  uint8_t data[3] = {0};
  touch_i2c_read(AXS5106L_ADDR, AXS5106L_ID_REG, data, 3);
}

void bsp_touch_read() {
  uint8_t data[14] = {0};
  g_touch_data.touch_num = 0;

  if (!g_touch_int_flag) {
    return;
  }
  g_touch_int_flag = false;

  touch_i2c_read(AXS5106L_ADDR, AXS5106L_TOUCH_DATA_REG, data, 14);

  g_touch_data.touch_num = data[1];
  if (g_touch_data.touch_num == 0) {
    return;
  }
  for (uint8_t i = 0; i < g_touch_data.touch_num; i++) {
    g_touch_data.coords[i].x = (static_cast<uint16_t>(data[2 + i * 6] & 0x0f)) << 8;
    g_touch_data.coords[i].x |= data[3 + i * 6];
    g_touch_data.coords[i].y = (static_cast<uint16_t>(data[4 + i * 6] & 0x0f)) << 8;
    g_touch_data.coords[i].y |= data[5 + i * 6];
  }
}

bool bsp_touch_get_coordinates(touch_data_t *touch_data) {
  if (touch_data == nullptr || g_touch_data.touch_num == 0) {
    return false;
  }

  for (uint8_t i = 0; i < g_touch_data.touch_num; i++) {
    switch (g_rotation) {
      case 1:
        touch_data->coords[i].y = g_touch_data.coords[i].x;
        touch_data->coords[i].x = g_touch_data.coords[i].y;
        break;
      case 2:
        touch_data->coords[i].x = g_touch_data.coords[i].x;
        touch_data->coords[i].y = g_height - 1 - g_touch_data.coords[i].y;
        break;
      case 3:
        touch_data->coords[i].y = g_height - 1 - g_touch_data.coords[i].x;
        touch_data->coords[i].x = g_width - 1 - g_touch_data.coords[i].y;
        break;
      default:
        touch_data->coords[i].x = g_width - 1 - g_touch_data.coords[i].x;
        touch_data->coords[i].y = g_touch_data.coords[i].y;
        break;
    }
  }
  touch_data->touch_num = g_touch_data.touch_num;
  return true;
}

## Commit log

2026-09-05 readme and basic schematic
2026-09-05 PWM to fan
2026-09-05 display and printer USB powered
2026-09-06 pwm back
2026-09-07 stl init
    [case_bottom.stl, case_top.stl]
2026-09-07 3d model case
2026-09-08 cable hole on bottom
    [case_bottom.stl, case_top.stl]
2026-09-09 led control
2026-09-14 fixed oled i2c pins
    [main_c3oled.cpp]
2026-09-19 pin changes
